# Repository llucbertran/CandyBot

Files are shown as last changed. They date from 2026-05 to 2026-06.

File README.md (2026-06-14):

# CandyBot

A voice-controlled candy dispenser built on a Raspberry Pi. A user asks for sweets out
loud — in **Catalan or Spanish** — and the robot serves the requested colours and amounts.
It also sorts itself: a rotating tray feeds Skittles one by one past a camera, reads
each colour, and drops it into the matching container.

Developed for the **Robotics Lab (RLP)** course at the Universitat Autònoma de Barcelona.

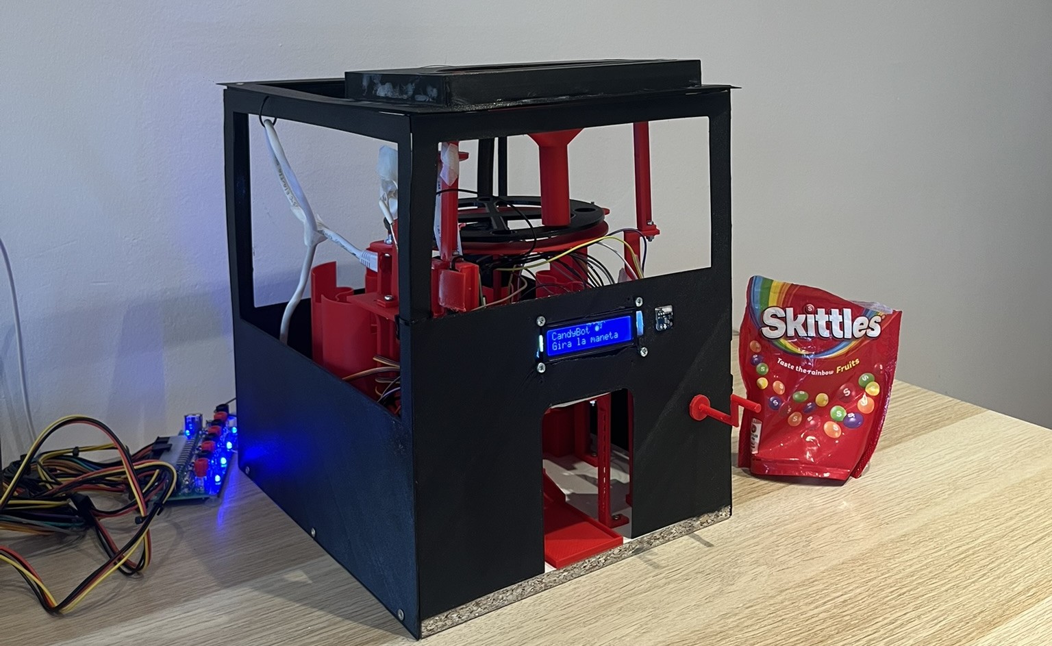
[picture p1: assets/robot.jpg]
CandyBot


[▶ Watch the demo](https://youtu.be/PrirMlMhzKU) *(Catalan with English subtitles)*

> **Autism & HRI.** Sorting and ordering objects is a well-documented self-regulatory
> behavior across the autism spectrum — it introduces predictability into a sensory
> environment that can feel overwhelming, and the act of categorising provides a
> satisfying, calming loop. CandyBot engages that same tendency in a playful context,
> while also offering a novel interaction modality: voice combined with a physical crank,
> which reduces the social pressure of direct human interaction.
>
> Color choices were informed by consultations with professionals in the field. Research
> shows that highly saturated or bright colors can be overstimulating for many individuals
> with ASD, while neutral, muted tones tend to be more comfortable. That said, autism is
> a broad spectrum and no single palette works universally — a conclusion reinforced by
> the professionals consulted during development. The robot's exterior is therefore black:
> visually quiet, non-imposing, and unobtrusive in any environment. The interior uses red
> accents to draw the user's attention and spark curiosity, without making the robot
> visually dominant in the space around it.

---

# Table of Contents

- [How it works](#how-it-works)
- [System architecture](#system-architecture)
  - [Pi software (BotSoftware)](#pi-software-botsoftware)
  - [Cloud API](#cloud-api)
- [Colour vision](#colour-vision)
  - [Detection pipeline](#detection-pipeline)
  - [HSV classification](#hsv-classification)
- [3D designs](#3d-designs)
- [Dispensing flow](#dispensing-flow)
- [Reload / self-sorting flow](#reload--self-sorting-flow)
- [Stock management](#stock-management)
- [Repository layout](#repository-layout)
- [Hardware](#hardware)
  - [Bill of materials](#bill-of-materials)
  - [Servo channel map](#servo-channel-map)
  - [Wiring defaults](#wiring-defaults)
- [The API](#the-api)
  - [Endpoint reference](#endpoint-reference)
  - [LLM prompt design](#llm-prompt-design)
  - [Deployment](#deployment)
- [Running the robot](#running-the-robot)
  - [Requirements](#requirements)
  - [Configuration](#configuration)
  - [Start](#start)
  - [Testing subsystems individually](#testing-subsystems-individually)
  - [Developing without hardware](#developing-without-hardware)
- [Team](#team)
- [License](#license)

---

# How it works

```
┌──────────────────────────────────────────────────────────────────┐
│  1. User turns crank   →  reed switch pulses  →  Pi starts rec.  │
│  2. Crank stops        →  WAV clip posted to Cloud API           │
│  3. API: STT           →  Gemini LLM          →  JSON command    │
│  4. Pi: dispense / reload / cancel            →  LCD feedback    │
└──────────────────────────────────────────────────────────────────┘
```

1. **Crank input.** A magnet sweeps past a reed switch once per revolution.
   The Pi counts pulses to detect user activity and starts recording automatically
   — no buttons, no touch screen.

2. **Recording.** While the crank is turning, audio is streamed to a buffer.
   When the crank stops, the clip is closed and sent as a WAV file to the
   CandyBot API over HTTPS.

3. **Language understanding.** The API pipeline has two stages:
   - **Speech-to-Text (Google STT v2)** transcribes the audio, tuned for Catalan
     (`ca-ES`).
   - **Gemini 2.5 Flash (Vertex AI)** reads the transcript and emits a strict JSON
     command describing what the user asked for.

4. **Execution.** The Pi interprets the JSON command and runs the matching flow:
   dispense specific colours and amounts, run the self-sorting reload routine, or
   do nothing if the intent was unclear.

Throughout the interaction the LCD screen shows the current state (idle, listening,
dispensing a colour, low stock warning, etc.).

---

# System architecture

## Pi software (BotSoftware)

The on-device code follows a **controller-per-subsystem** pattern. Each controller
owns one piece of hardware and exposes a small, stable interface to the rest of
the system.

```
BotSoftware/main.py
  │
  ├── crank_controller   — GPIO reed switch, wait_for_turn(), is_turning()
  ├── display_controller — 16×2 LCD, named states (idle, listening, dispensing…)
  ├── candy_controller   — stock check → servo dispatch → stock update
  ├── reload_controller  — disk + camera loop with voice-cancel support
  ├── servo_controller   — PCA9685 driver, dispense(color, qty), ramp_to(color)
  └── vision_controller  — picamera2 frame capture + ROI colour classification
```

The main loop is intentionally simple:

```python
while True:
    display.idle()
    crank.wait_for_turn()          # blocks until crank spins
    display.listening()
    response = api_client.record_and_send_while(crank.is_turning)

    if response["action"] == "dispense":
        candy_controller.dispense(response["items"])
    elif response["action"] == "reload":
        reload_controller.reload_with_voice_cancel()
    # cancel / nothing → loop back
```

## Cloud API

The API is a **FastAPI** application containerised with Docker and deployed to
**Google Cloud Run**. It is stateless: each request is fully self-contained.

```
POST /v1/command
  │
  ├── validate content-type and file size
  ├── Google STT v2  →  transcript (str)
  ├── Gemini 2.5 Flash  →  raw JSON (str)
  ├── pydantic parse + validate  →  CandyBotResponse
  └── return JSON response
```

Request authentication uses a shared secret passed in the `X-API-Token` header.
Timing for each stage (STT, LLM, total) is logged at INFO level on every request.

---

# Colour vision

## Detection pipeline

The vision system runs a **persistent picamera2 stream** at ~30 fps with fixed
exposure and gain, ensuring colour consistency across frames. During reload, the
system inspects a small ROI at a fixed position in the frame — the point where
each candy slot passes under the lens.

```
picamera2 frame (640 × 480)
  │
  ├── extract ROI  (centred at 40 % × 50 % of frame, radius 7 % of width)
  ├── convert BGR → HSV
  ├── compute median H, S, V across the ROI
  │
  ├── reject: H ≤ 12                        → disk hue wrapping near 0
  ├── reject: H 148–179 + V < 130 + S < 200 → black disk surface
  ├── reject: V < 20                         → too dark (shadow / gap)
  ├── reject: S < 120                        → empty slot / background
  │
  └── classify: nearest reference hue (circular distance) → colour name
```

A **two-consecutive-frames** confirmation rule (in `reload_controller`) prevents
stray reflections or partial coverage from triggering a wrong bin assignment.

## HSV classification

OpenCV uses H ∈ [0, 179]. Each colour is represented by a single reference hue;
classification picks the closest one by circular distance.

| Colour | Default reference hue |
|---|---|
| green  | 45 |
| yellow | 95 |
| orange | 121 |
| red | 135 |
| purple | 172 |

Reference hues are loaded at startup from `BotSoftware/VC/color_calibration.json`
if the file exists. Run `HW tests/calibrar_colores.py` to measure and save the
per-unit hues for your specific camera and lighting conditions.

---

# Dispensing flow

When the command action is `"dispense"`:

```
candy_controller.dispense(items)
  │
  ├── guard: items list empty?  →  display.empty_command()
  ├── check_availability(items) against SQLite stock
  │     not ok  →  display.low_stock(color, available)  →  return
  │
  └── for each item:
        display.dispensing(color, qty)
        servo_controller.dispense(color, qty)   # SG90 pulses
        (loop qty times, one candy per pulse)
  │
  └── consume_from_command(items)   →  update SQLite
```

`servo_controller.dispense` sends a calibrated angular pulse to the SG90 on the
matching PCA9685 channel. Each pulse ejects exactly one Skittle from its cylinder.
The number of pulses equals the requested quantity.

---

# Reload / self-sorting flow

When the command action is `"reload"`, the robot enters the self-sorting routine.
A background thread simultaneously listens for a voice `"cancel"` command so the
user can stop the reload early by turning the crank and saying "para".

```
reload_with_voice_cancel()
  │
  ├── spawn listener thread:
  │     while not cancelled and not done:
  │         if crank.is_turning():
  │             record → API → if action=="cancel": set cancel_event
  │
  └── reload_once(should_cancel=cancel_event.is_set)
        │
        ├── vision_controller.start()   (open camera)
        ├── servo_controller.disk_start()   (continuous servo)
        │
        ├── loop:
        │     detect_color() → color
        │     require two consecutive same-colour frames (anti-flicker)
        │     if confirmed and armed:
        │         sleep DISK_RAMP_DELAY_S   (candy travels to ramp)
        │         servo_controller.ramp_to(color)
        │         candy_stock.add_candy(color, 1)
        │         display.reloading(stock, color)
        │         armed = False
        │     if no candy for DISK_REARM_S  →  armed = True
        │     if no candy for DISK_EMPTY_TIMEOUT_S  →  break (tray empty)
        │     sleep CAMERA_INTERVAL_S
        │
        └── disk_stop() · ramp_center() · vision_controller.release()
```

All timing constants (`DISK_RAMP_DELAY_S`, `DISK_REARM_S`, `DISK_EMPTY_TIMEOUT_S`,
`CAMERA_INTERVAL_S`) are defined in `BotSoftware/config/servo_config.py` so they
can be tuned without touching controller logic.

---

# Stock management

Stock is persisted in a **SQLite database** (`BotSoftware/candy_stock.db`).
The schema is a single table:

```sql
CREATE TABLE stock (
    color    TEXT PRIMARY KEY,
    quantity INTEGER NOT NULL DEFAULT 0 CHECK (quantity >= 0)
);
```

Five rows are seeded on first use (red, orange, yellow, green, purple).
The public API exposed by `BotSoftware/models/candy_stock.py`:

| Function | Description |
|---|---|
| `get_stock(color=None)` | Return quantity for one colour, or a dict of all five |
| `add_candy(color, qty)` | Increment stock (called by reload loop) |
| `remove_candy(color, qty)` | Decrement stock (called after dispensing) |
| `set_stock(color, qty)` | Overwrite a single colour (calibration / tests) |
| `set_all(qty)` | Set every colour to the same value |
| `reset()` | Empty all stock (every colour → 0) |
| `check_availability(items)` | Return `{ok, missing}` before dispensing |
| `consume_from_command(items)` | Atomic check-and-remove for a full command |

The `CHECK (quantity >= 0)` constraint in SQLite means stock can never go
negative at the database level, even if a software bug skips the availability
check.

---

# Repository layout

```
CandyBot/
│
├── BotSoftware/                Code that runs on the Raspberry Pi
│   ├── main.py                 Entry point — the main loop
│   ├── candy_stock.db          SQLite stock database (created on first run)
│   ├── config/
│   │   └── servo_config.py     I2C addresses, GPIO pins, timing constants
│   ├── controllers/
│   │   ├── candy_controller.py   Dispense flow
│   │   ├── crank_controller.py   Reed switch input
│   │   ├── display_controller.py LCD states
│   │   ├── reload_controller.py  Self-sorting flow
│   │   ├── servo_controller.py   PCA9685 / SG90 driver
│   │   └── vision_controller.py  Camera capture + colour classification
│   ├── models/
│   │   └── candy_stock.py        SQLite stock access layer
│   ├── services/
│   │   └── api_client.py         Audio recording + HTTP post to API
│   └── VC/                       Vision module
│       ├── camera_stream.py      Picamera2 continuous capture
│       ├── color_centre.py       ROI extraction + HSV hue classification
│       ├── color_calibration.json  Per-unit hue calibration (generated)
│       └── prototypes/           Standalone development scripts
│
├── Software/
│   └── Api/                        Cloud service (FastAPI + Docker)
│       ├── main.py                 FastAPI app, /v1/command endpoint
│       ├── config.py               Settings via environment variables
│       ├── models.py               Pydantic response schema
│       ├── Dockerfile              Container definition
│       ├── pyproject.toml          Poetry dependencies
│       └── services/
│           ├── llm_client.py       Vertex AI / Gemini 2.5 Flash client
│           ├── speech_to_text.py   Google STT v2 client
│           ├── parse_and_validate.py   JSON parse + pydantic validation
│           ├── prompt_loader.py    Load system prompt from file
│           └── system_prompt.txt   LLM system prompt
│
├── HW tests/                   Standalone hardware verification scripts
│   ├── test_palanca.py         Crank / reed switch
│   ├── test_ordenar.py         Full sorting cycle (tray + camera + ramp)
│   ├── test_pantalla.py        LCD display
│   ├── control_servo_basic.py  Raw servo movement
│   ├── control_pantallaLCD_basic.py  Raw LCD output
│   ├── calibrar_colores.py     Calibrate per-unit colour reference hues
│   └── ver_colores.py          Live colour detection preview
│
└── 3D Models/                  Printable parts (.stl) — being finalised
```

---

# Hardware

## Bill of materials

| Qty | Part | Role |
|-----|---|---|
| 1 | Raspberry Pi 4 (4 GB) | Central controller |
| 1 | Raspberry Pi Camera Module v2 | Colour detection |
| 1 | PCA9685 16-ch PWM driver (I2C) | Servo bus |
| 5 | SG90 servo | Candy dispensers (one per colour) |
| 1 | SG90 servo | Directional ramp |
| 1 | Continuous-rotation servo (360°) | Sorting tray disk |
| 1 | 16×2 character LCD + PCF8574 I2C backpack | User feedback |
| 1 | USB sound card + electret microphone | Voice input |
| 1 | Reed switch + neodymium magnet | Crank activity detection |
| — | 5 V power supply (≥ 3 A) | Servo rail |

## Servo channel map

| PCA9685 channel | Servo | Colour |
|---|---|---|
| 0 | Dispenser | green |
| 1 | Dispenser | purple |
| 2 | Dispenser | red |
| 3 | Dispenser | orange |
| 4 | Dispenser | yellow |
| 5 | Ramp | — |
| 6 | Sorting disk | — |

Channels 5 and 6 are assigned during assembly and may differ per build.
Verify against `BotSoftware/config/servo_config.py` before first run.

## Wiring defaults

| Component | Default address / pin |
|---|---|
| PCA9685 | I2C `0x40` |
| LCD | I2C `0x3F` |
| Reed switch | GPIO 17 (BCM) |
| Microphone | ALSA `plughw:1,0` |
| Camera | Pi camera port (CSI), via picamera2 |

Find your microphone device with `arecord -l`. Update `servo_config.py` if your
I2C addresses differ (use `i2cdetect -y 1` to scan the bus).

---

# 3D designs

All structural and mechanical parts are custom-designed for this project from
scratch. Designs stem from research and inspiration from existing mechanisms,
adapted and shaped to fit CandyBot's specific requirements.

The final design comprises around **29 distinct printable parts**, though many more
were designed along the way — early prototypes, intermediate versions, and parts
that were later corrected or replaced as the design evolved.

Each part went through several design iterations, guided by two priorities:
**ease of maintenance** — individual parts can be removed and replaced without
disassembling the whole robot — and **robust assembly**, using screwed joints
throughout to avoid snap fits that degrade over time.

Dimensional accuracy was especially critical for the moving mechanisms. The
sorting tray, the dispensers, and the directional ramp all depend on tight
tolerances: even small deviations in a sliding or rotating part introduce
friction that disrupts the timing of the sorting cycle.

<table>
  <tr>
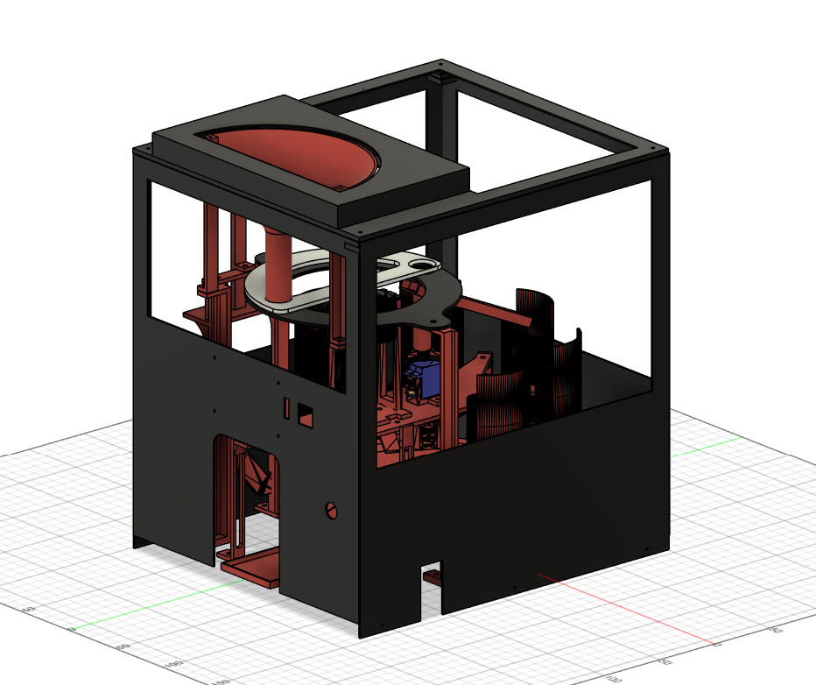
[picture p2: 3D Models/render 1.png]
    <td></td>
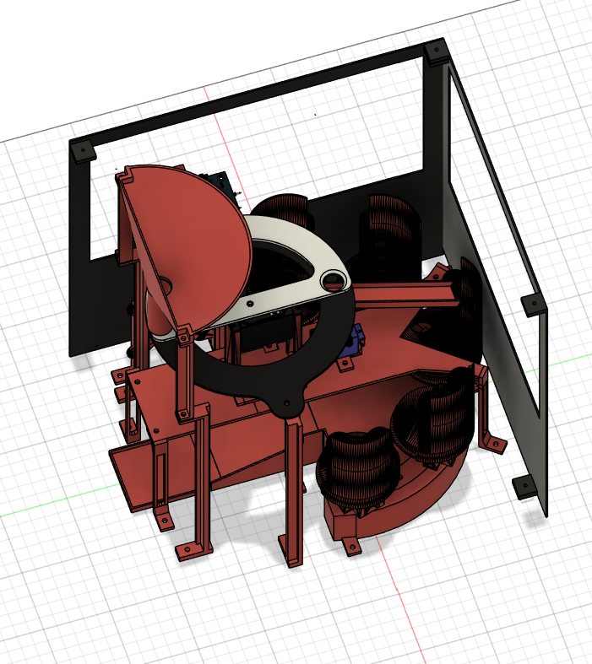
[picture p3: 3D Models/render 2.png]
    <td></td>
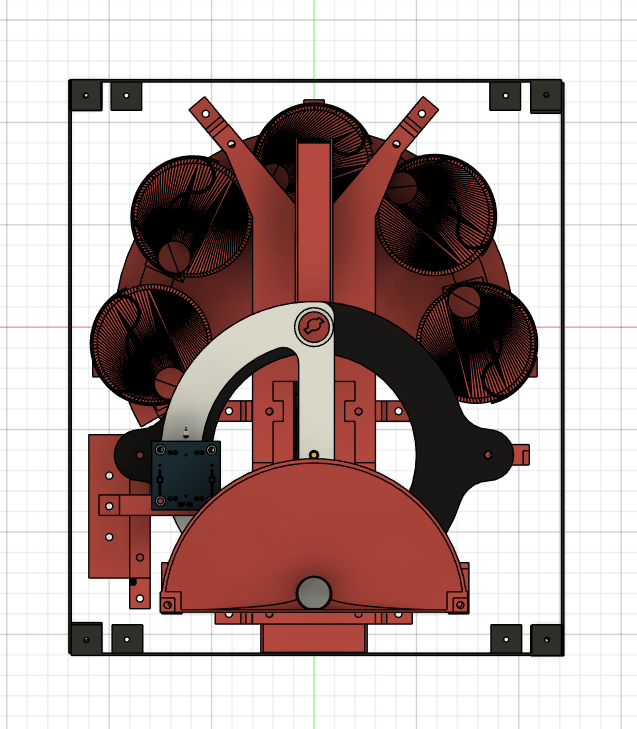
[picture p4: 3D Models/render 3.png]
    <td></td>
  </tr>
  <tr>
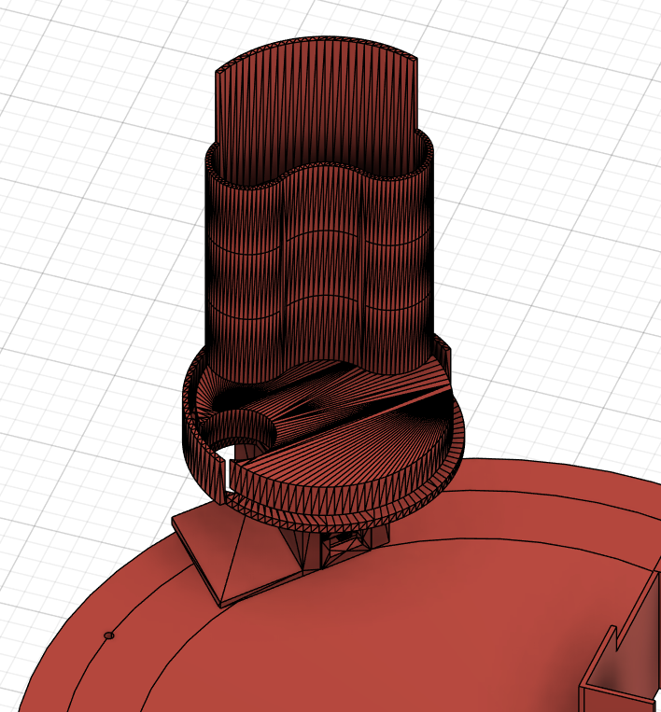
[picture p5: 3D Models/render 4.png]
    <td></td>
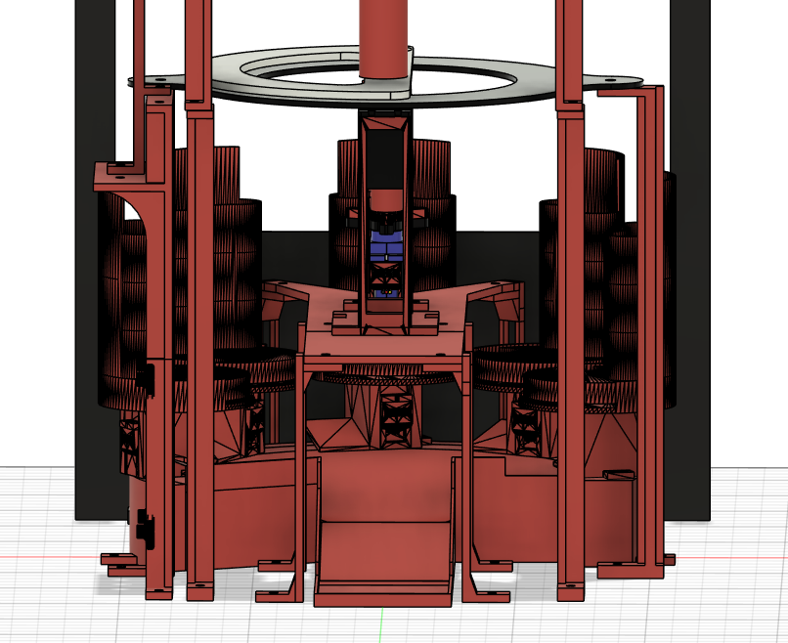
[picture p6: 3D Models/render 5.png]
    <td></td>
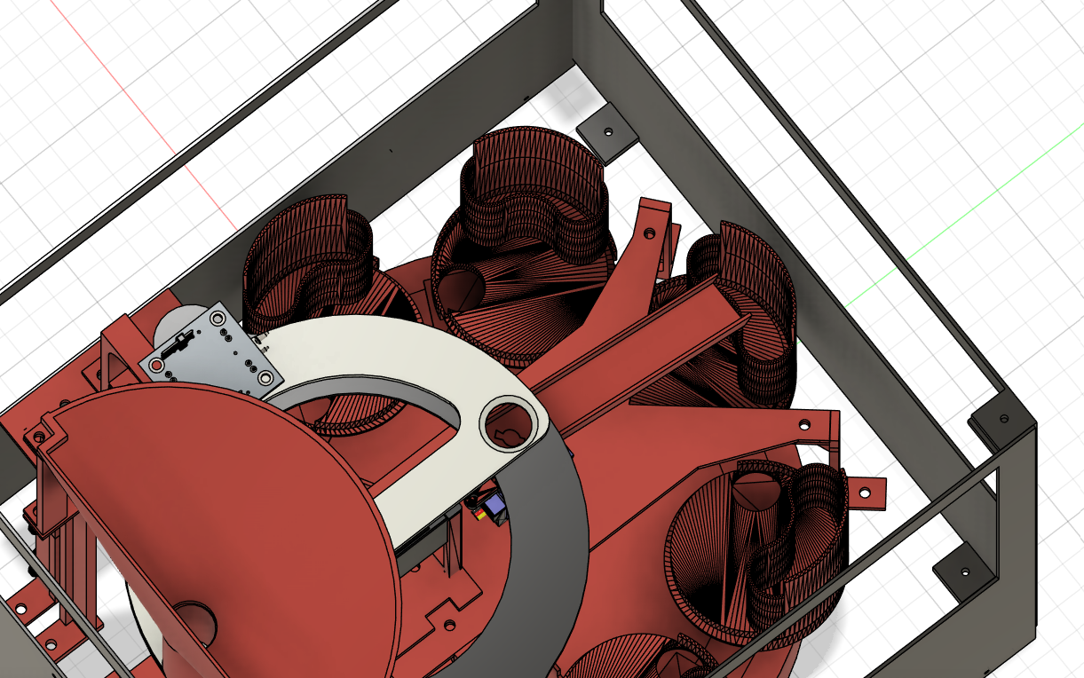
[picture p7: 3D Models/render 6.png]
    <td></td>
  </tr>
</table>

STL files are available in `3D Models/`.

> **Note:** The sorting disk shown in some renders is an earlier single-slot design that required the disk to oscillate back and forth for each candy. The final version uses a **continuous-rotation disk with 4 slots**, eliminating the back-and-forth motion and multiplying sorting throughput by 4×.

---

# The API

## Endpoint reference

### `GET /health`

Health check. Returns `{"status": "ok", "service": "CandyBot API"}`. No authentication required.

### `POST /v1/command`

Convert a voice clip to a structured candy command.

**Authentication:** `X-API-Token: <token>` header (required).

**Request body:** `multipart/form-data`

| Field | Type | Description |
|---|---|---|
| `audio` | file | WAV audio clip. Content-Type must start with `audio/`. Max size controlled by `MAX_AUDIO_BYTES` env var. |

**Response** `200 OK`:

```json
{
  "action":     "dispense",
  "confidence": 0.95,
  "items": [
    { "color": "red",    "quantity": 2 },
    { "color": "yellow", "quantity": 1 }
  ]
}
```

| Field | Type | Values |
|---|---|---|
| `action` | string | `dispense` · `reload` · `cancel` · `nothing` |
| `confidence` | float | 0.0 – 1.0, LLM self-reported |
| `items` | array | Only present when `action == "dispense"` |

**Error responses:**

| Status | Cause |
|---|---|
| 400 | Invalid content-type, empty file, or file too large |
| 401 | Missing or invalid `X-API-Token` |
| 422 | LLM returned a response that failed schema validation |
| 502 | Upstream STT or LLM request failed |

## LLM prompt design

The system prompt (`Software/Api/services/system_prompt.txt`) instructs Gemini to:

- Output **only valid JSON**, matching the `CandyBotResponse` schema.
- Map colour names from Catalan and Spanish to the canonical English set
  (`red`, `orange`, `yellow`, `green`, `purple`).
- Set `action = "nothing"` when the intent is unclear or unrelated.
- Set `action = "cancel"` when the user explicitly wants to stop.
- Report a `confidence` value reflecting certainty about the parsed intent.

The LLM is called with `response_mime_type: "application/json"` so that
Gemini returns structured output natively, reducing parse failures.

## Deployment

The API is containerised and tested to run on **Google Cloud Run** (minimum
512 MB memory; the STT and Vertex AI clients add no in-process weight beyond
the Python SDK).

**Environment variables:**

| Variable | Required | Default | Description |
|---|---|---|---|
| `GCP_PROJECT` | yes | — | Google Cloud project ID |
| `GCP_LOCATION` | no | `europe-west1` | Region for Vertex AI |
| `API_TOKEN` | yes | — | Shared secret for authentication |
| `MAX_AUDIO_BYTES` | no | `10485760` | Max upload size (10 MB) |
| `LLM_MODEL` | no | `gemini-2.5-flash` | Vertex AI model name |

**Required Google Cloud APIs:** Speech-to-Text v2, Vertex AI.

Build and run locally:

```bash
cd Api
docker build -t candybot-api .
docker run -p 8080:8080 \
  -e GCP_PROJECT=my-project \
  -e GCP_LOCATION=europe-west1 \
  -e API_TOKEN=mysecret \
  candybot-api
```

---

# Running the robot

## Requirements

- Raspberry Pi running **Raspberry Pi OS** (Bookworm or later), Python 3.11+
- Hardware connected and verified (see [Hardware](#hardware))
- Python packages:

  ```
  requests
  python-dotenv
  gpiozero
  adafruit-servokit
  RPLCD
  opencv-python
  picamera2
  ```

- System tools (pre-installed on Raspberry Pi OS):

  ```
  arecord   # ALSA audio recording
  ```

Install Python dependencies:

```bash
pip install requests python-dotenv gpiozero adafruit-servokit RPLCD opencv-python picamera2
```

## Configuration

Create a `.env` file inside `BotSoftware/`:

```env
API_URL=https://<your-cloud-run-url>/v1/command
API_TOKEN=<the same token configured in the API>
```

Review `BotSoftware/config/servo_config.py` and verify that I2C addresses,
GPIO pin, microphone device, and servo channels match your build before
the first run.

## Start

```bash
python -m BotSoftware.main
```

The robot enters idle state, waits for crank input, then loops indefinitely.

## Testing subsystems individually

Before a full run it is recommended to verify each subsystem in isolation:

```bash
# Crank / reed switch
python "HW tests/test_palanca.py"

# LCD display
python "HW tests/test_pantalla.py"

# Sorting cycle: tray motor, camera, ramp
python "HW tests/test_ordenar.py"

# Dispense one candy of each colour
python -m BotSoftware.controllers.servo_controller

# Microphone + speech-to-text smoke test
python "HW tests/speech_to_text.py"

# Raw servo movement
python "HW tests/control_servo_basic.py"
```

## Developing without hardware

Every controller guards its hardware import with a try/except. If a component
(PCA9685, LCD, camera, GPIO) is not found, the controller prints a `[NO HW]`
notice and continues in **simulation mode** — methods become no-ops or return
dummy values. This means the full software stack can be run and tested on any
machine, even without a Raspberry Pi attached.

---

# Team

Developed at the Robotics Lab (RLP), Universitat Autònoma de Barcelona.

| Role | Name |
|---|---|
| Software Lead | Pol Montesó Tarrida |
| Hardware Lead | Xavi Umbert Medina |
| 3D Parts & Mechanical Lead / Product Owner | Lluc Bertran Canicio |
| Testing & Validation Lead | Matheus Henrique Mingorance Maciel |
| Vision Lead | Matheus Henrique Mingorance Maciel |

See [Roles.md](Roles.md) for full role descriptions.

---

# License

MIT

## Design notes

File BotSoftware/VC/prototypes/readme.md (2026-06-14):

> **Nota:** Aquesta carpeta conté prototips inicials de visió per computador. No
> formen part del sistema final, que utilitza `BotSoftware/VC/color_centre.py` i
> `camera_stream.py`. Es conserven com a documentació de la investigació.

# Detecció de color de Skittles amb Visió per Computador

Aquest directori conté un petit programa en Python per detectar automàticament el color d'un Skittle a partir d'imatges capturades amb càmera.

El codi utilitza **OpenCV** i **NumPy** per processar les imatges, localitzar l'objecte principal i classificar el seu color mitjançant l'espai de color **HSV**.

---

## Objectiu

L'objectiu és provar una primera versió del sistema de visió per computador que més endavant es podria executar en una Raspberry Pi amb càmera.

En aquesta prova, no s'utilitza encara la Raspberry Pi. Les imatges ja estan capturades prèviament i el programa les analitza des d'un ordinador.

El sistema:

1. Llegeix totes les imatges d'una carpeta.
2. Detecta l'objecte circular que correspon al Skittle.
3. Calcula el color dominant del Skittle.
4. Classifica el color.
5. Mostra la imatge amb la detecció marcada.
6. Imprimeix un resum final amb el color detectat per cada imatge.

---

## Fitxers

Exemple d'estructura de la carpeta:

```txt
VC/
├── detectar_colors.py
├── prova1.jpg
├── prova2.jpg
├── prova3.jpg
├── prova4.jpg
├── prova5.jpg
├── prova6.jpg
└── README.md
```

Les imatges de prova són:

```txt
prova1.jpg
prova2.jpg
prova3.jpg
prova4.jpg
prova5.jpg
prova6.jpg
```

Cada imatge conté un Skittle d'un color diferent.

---

## Requisits

Cal tenir instal·lat Python i les llibreries següents:

```bash
pip install opencv-python numpy
```

Si `pip` no funciona directament, es pot provar:

```bash
py -m pip install opencv-python numpy
```

---

## Execució

Des de la carpeta on es troben les imatges i el fitxer `detectar_colors.py`, executar:

```bash
python detectar_colors.py
```

o bé:

```bash
py detectar_colors.py
```

---

## Funcionament general del codi

El programa segueix aquest procés:

```txt
Llegir imatge
↓
Convertir imatge de BGR a HSV
↓
Crear una màscara de zones amb color viu
↓
Buscar contorns
↓
Seleccionar el contorn que més sembla un Skittle
↓
Calcular el color dominant
↓
Classificar el color
↓
Mostrar resultat
```

---

## Per què s'utilitza HSV?

Les imatges que llegeix OpenCV estan en format **BGR**, però per detectar colors és més còmode utilitzar **HSV**.

HSV separa la informació en:

```txt
H = Hue / To del color
S = Saturation / Intensitat del color
V = Value / Brillantor
```

Això permet diferenciar millor colors com:

- blau,
- verd,
- groc,
- taronja,
- vermell,
- marró.

Per exemple, dos colors poden semblar semblants en RGB, però en HSV es poden separar millor segons el seu to, saturació i brillantor.

---

## Lectura robusta d'imatges

El codi no utilitza directament:

```python
cv2.imread()
```

perquè en Windows pot donar problemes quan la ruta conté accents o caràcters especials, com per exemple:

```txt
Pràctiques
```

Per això es fa servir una lectura més robusta:

```python
datos = np.fromfile(str(ruta_imagen), dtype=np.uint8)
imagen = cv2.imdecode(datos, cv2.IMREAD_COLOR)
```

Això evita errors de lectura de fitxers en rutes amb accents.

---

## Cerca automàtica d'imatges

El programa busca automàticament imatges dins la carpeta actual.

Accepta extensions:

```txt
.jpg
.jpeg
.JPG
.JPEG
.png
.PNG
```

A més, evita duplicats, ja que en Windows les extensions `.jpg` i `.JPG` poden arribar a detectar el mateix fitxer dues vegades.

---

## Detecció del Skittle

Primer es crea una màscara per detectar zones amb color viu:

```python
lower = np.array([0, 70, 45])
upper = np.array([179, 255, 255])
mascara = cv2.inRange(hsv, lower, upper)
```

Aquesta màscara intenta quedar-se amb les parts de la imatge que tenen color suficient i descartar parts com:

- fons de fusta,
- ombres,
- zones grises,
- reflexos poc saturats.

Després es busquen contorns amb:

```python
cv2.findContours()
```

---

## Selecció del contorn correcte

Inicialment, el programa agafava el contorn més gran, però això podia fallar perquè altres zones de la imatge, com objectes a la part inferior, també tenien colors vius.

Per solucionar-ho, ara el programa selecciona el contorn que més sembla un Skittle segons diversos criteris:

```txt
- Ha de tenir una àrea raonable.
- Ha de ser relativament circular.
- No pot tocar les vores de la imatge.
- No pot ser una regió massa gran.
- No pot ser massa allargat.
- Es prioritzen objectes propers al centre de la imatge.
```

Això permet evitar detectar erròniament altres objectes de la imatge.

---

## Càlcul del color dominant

Un cop detectat el contorn del Skittle, es crea una màscara només per aquest objecte.

Després es calculen els valors HSV dels píxels que pertanyen al Skittle.

Per evitar que els reflexos blancs o les ombres afectin massa, es filtra la saturació i es fa servir la **mediana** en comptes de la mitjana:

```python
h_median = float(np.median(pixels_h))
s_median = float(np.median(pixels_s))
v_median = float(np.median(pixels_v))
```

La mediana és més robusta que la mitjana perquè no es veu tan afectada per valors extrems, com reflexos molt blancs o zones molt fosques.

---

## Classificació del color

La funció principal de classificació és:

```python
clasificar_color_hsv(h, s, v)
```

Aquesta funció rep els valors HSV dominants i retorna un color.

Els rangs utilitzats són aproximadament:

```txt
H < 10 o H >= 170     -> vermell
10 <= H < 24          -> taronja
24 <= H < 40          -> groc
40 <= H < 85          -> verd
85 <= H < 130         -> blau
130 <= H < 160        -> lila / morat
```

També s'ha afegit una regla especial per detectar el color marró.

---

## Diferència entre vermell i marró

En HSV, el marró pot caure en una zona semblant al vermell o taronja. Per això no n'hi ha prou amb mirar només el valor `H`.

En les imatges de prova:

```txt
marró   -> H proper al vermell/taronja, però amb V baix i S més baixa
vermell -> H proper al vermell, però amb V alta i S alta
```

Per això el codi detecta el marró així:

```python
if (h < 20 or h >= 170) and v < 130 and s < 180:
    return "marro"
```

És a dir:

```txt
Si sembla vermell/taronja,
però és fosc i menys saturat,
llavors es classifica com a marró.
```

---

## Visualització del resultat

Per cada imatge, el programa mostra una finestra amb:

- la imatge original,
- un rectangle verd al voltant del Skittle,
- un punt al centre aproximat,
- el nom del fitxer,
- el color detectat.

Exemple visual:

```txt
prova1.jpg: blau
```

Per passar a la següent imatge, cal prémer qualsevol tecla mentre la finestra d'OpenCV està seleccionada.

---

## Resultat esperat

Un exemple de sortida per terminal és:

```txt
Resultats:
------------------------------------------------------------
prova1.jpg -> blau (H=115.0, S=255.0, V=211.0)
prova2.jpg -> groc (H=28.0, S=249.0, V=221.0)
prova3.jpg -> marro (H=9.0, S=115.0, V=70.0)
prova4.jpg -> taronja (H=14.0, S=243.0, V=223.0)
prova5.jpg -> verd (H=77.0, S=238.0, V=191.0)
prova6.jpg -> vermell (H=176.0, S=224.0, V=201.0)

RESUM FINAL
------------------------------------------------------------
prova1.jpg -> blau
prova2.jpg -> groc
prova3.jpg -> marro
prova4.jpg -> taronja
prova5.jpg -> verd
prova6.jpg -> vermell
```

---

## Colors detectats

Actualment el codi pot classificar:

```txt
blau
groc
marro
taronja
verd
vermell
lila / morat
rosa / vermell clar
blanc / gris clar
molt fosc / ombra
```

Els colors principals de la prova són:

```txt
blau
groc
marro
taronja
verd
vermell
```

---

## Limitacions

Aquest sistema és una primera versió basada en regles HSV.

Pot fallar si:

- canvia molt la il·luminació,
- hi ha ombres fortes,
- el fons té colors semblants al Skittle,
- el Skittle està molt lluny o molt petit,
- hi ha més d'un objecte circular de color a la imatge,
- la càmera canvia molt la saturació o la brillantor.

Per un sistema final, seria recomanable:

- controlar millor la il·luminació,
- fixar la posició de la càmera,
- posar un fons més neutre,
- calibrar els rangs HSV amb més imatges,
- guardar exemples de cada color,
- provar amb vídeo en temps real.

---

## Possible evolució amb Raspberry Pi

Aquest codi és una prova local amb imatges ja capturades.

Més endavant, en una Raspberry Pi, el flux seria:

```txt
Capturar imatge amb la càmera
↓
Executar detecció de color
↓
Classificar el Skittle
↓
Enviar ordre al robot o mecanisme de separació
```

Per exemple:

```txt
Si color = vermell -> moure servo a posició 1
Si color = blau    -> moure servo a posició 2
Si color = verd    -> moure servo a posició 3
```

---

## Resum

Aquest codi implementa una primera versió funcional d'un detector de color per Skittles utilitzant visió per computador.

La detecció es basa en:

- OpenCV,
- conversió a HSV,
- màscares de color,
- detecció de contorns,
- selecció de formes circulars,
- classificació del color dominant.

És una base inicial per al sistema de separació automàtica de Skittles del projecte.

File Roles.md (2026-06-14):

## 👥 Team Roles

This project is developed as part of the Robotics Lab (RLP) at UAB.

- 💻 **Software Lead (SW Lead)**  
  Pol Montesó Tarrida  

- 🔩 **Hardware Lead (HW Lead)**  
  Xavi Umbert Medina  

- 🛠️ **3D Parts & Mechanical Lead + Product Owner (PO)**  
  Lluc Bertran Canicio  

- 🔬 **Testing & Validation Lead**  
  Matheus Henrique Mingorance Maciel  

- 👁️ **Vision Lead**  
  Matheus Henrique Mingorance Maciel

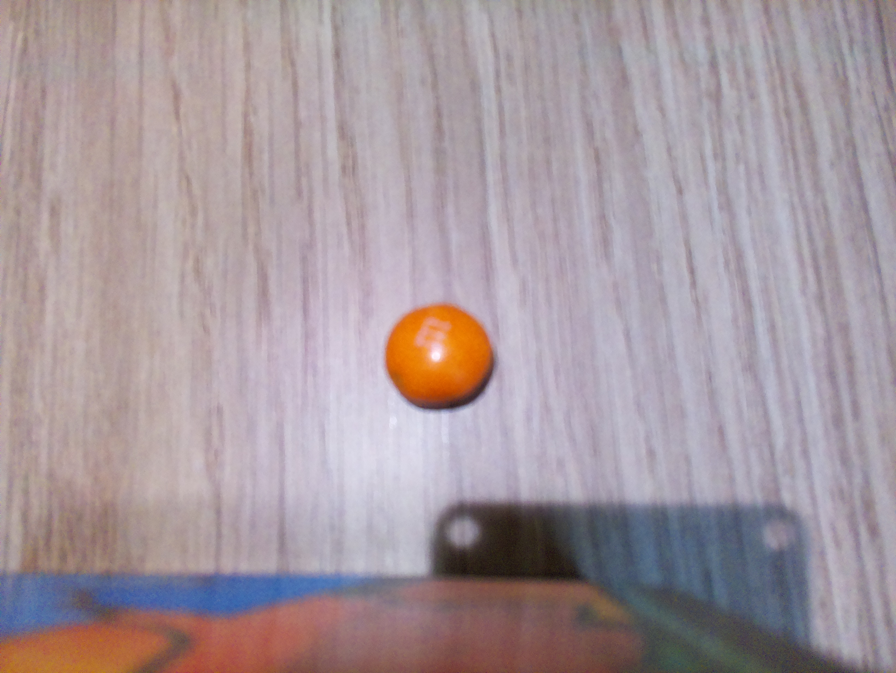
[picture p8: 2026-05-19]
BotSoftware/VC/prototypes/prova4.jpg

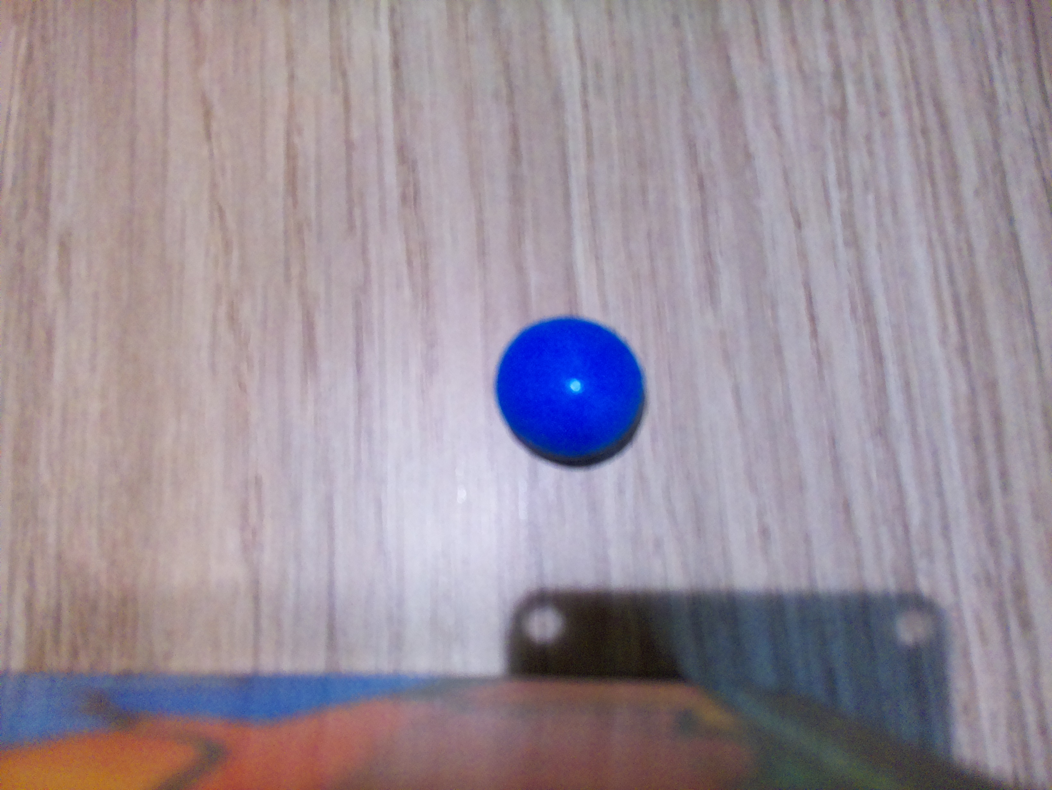
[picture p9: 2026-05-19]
BotSoftware/VC/prototypes/prova1.jpg

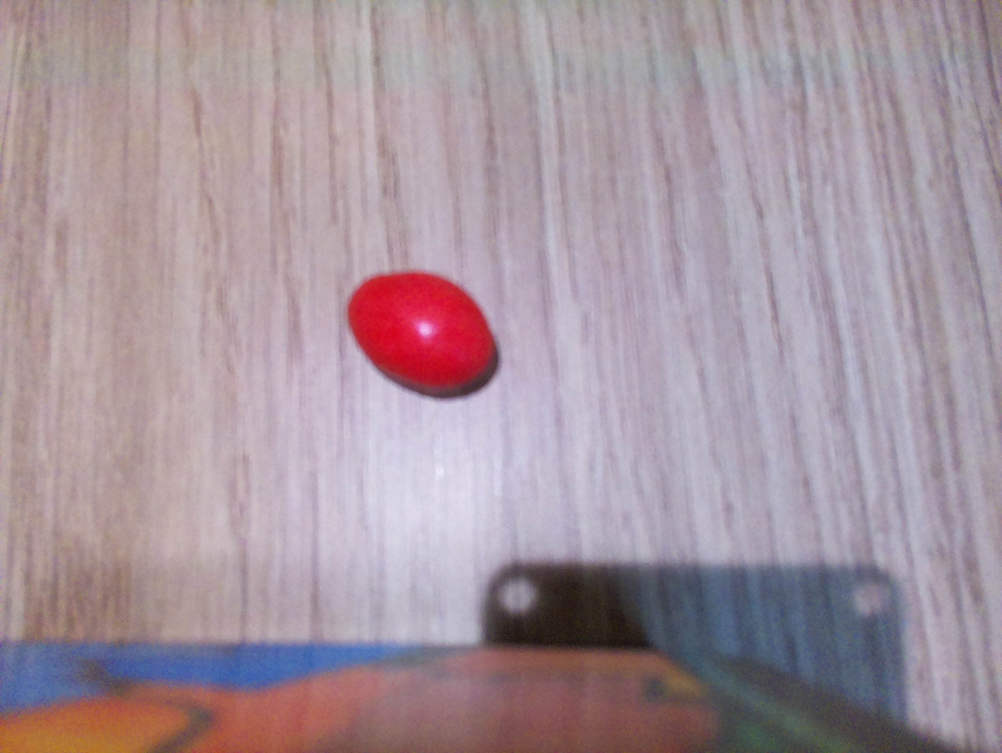
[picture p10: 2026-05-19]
BotSoftware/VC/prototypes/prova6.jpg

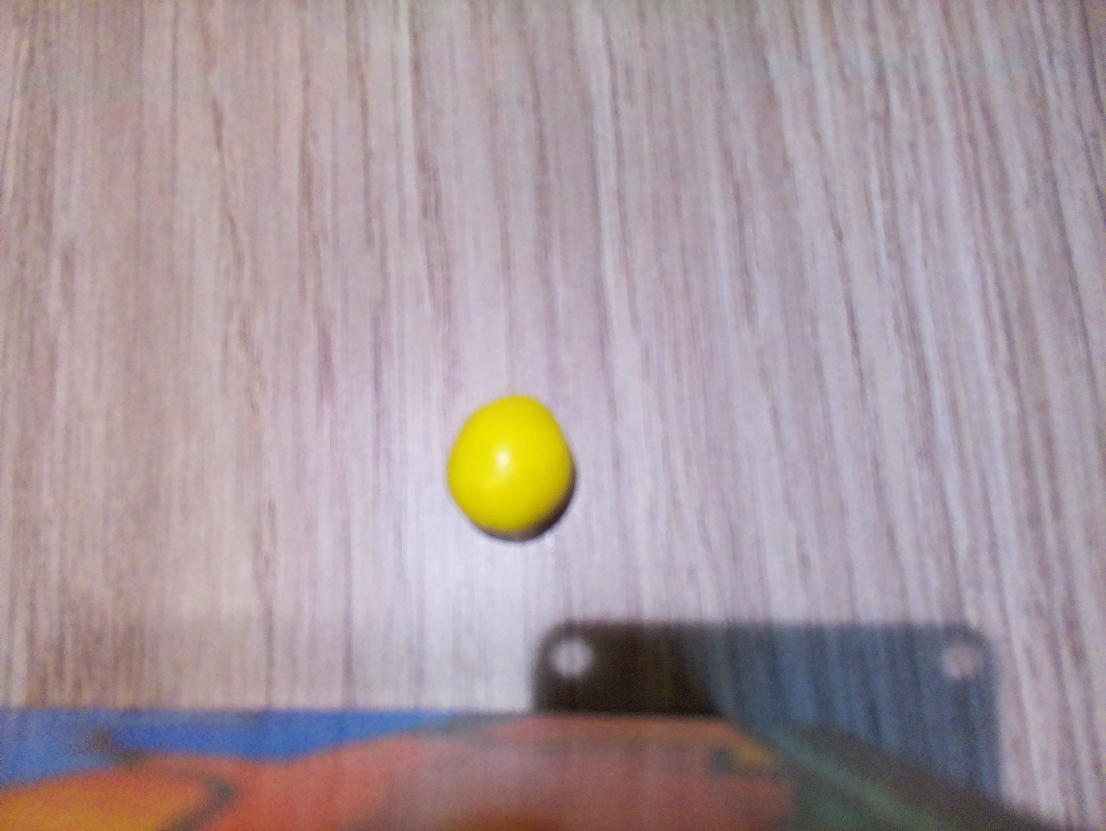
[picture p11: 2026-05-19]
BotSoftware/VC/prototypes/prova2.jpg

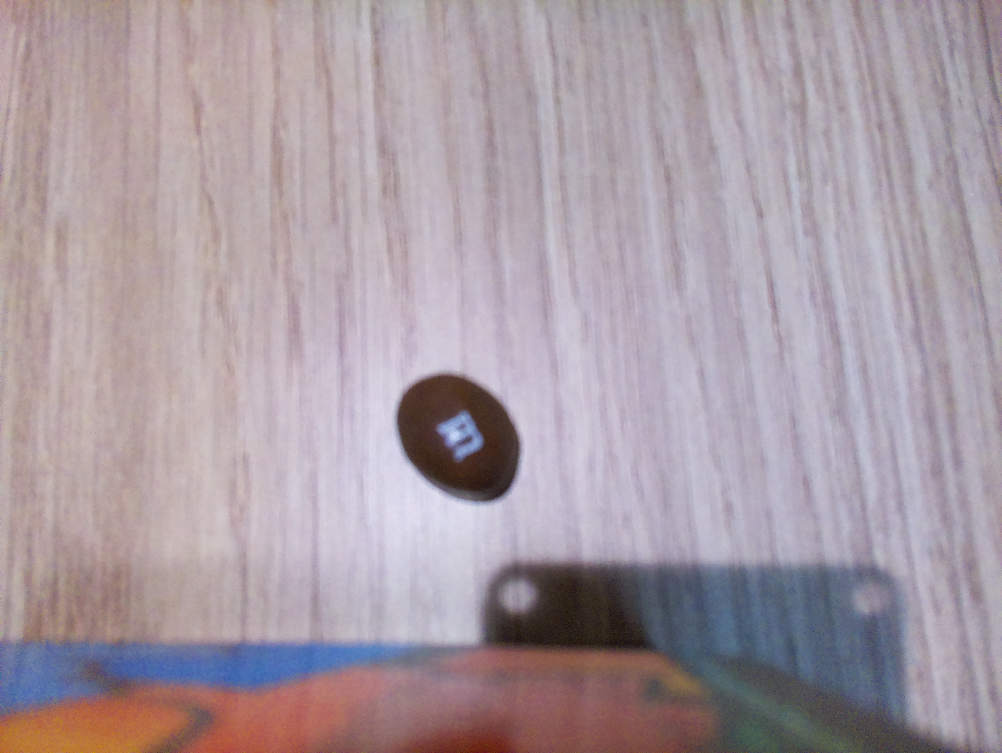
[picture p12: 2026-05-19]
BotSoftware/VC/prototypes/prova3.jpg

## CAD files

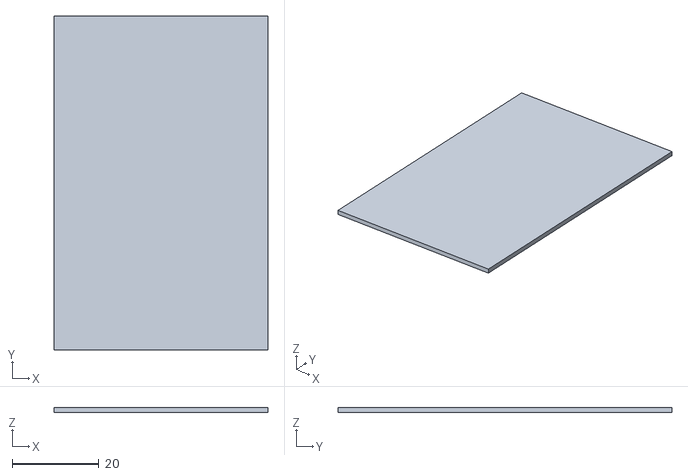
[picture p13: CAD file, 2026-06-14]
3D Models/main base ramp.stl
49.2 x 76.9 x 1.20

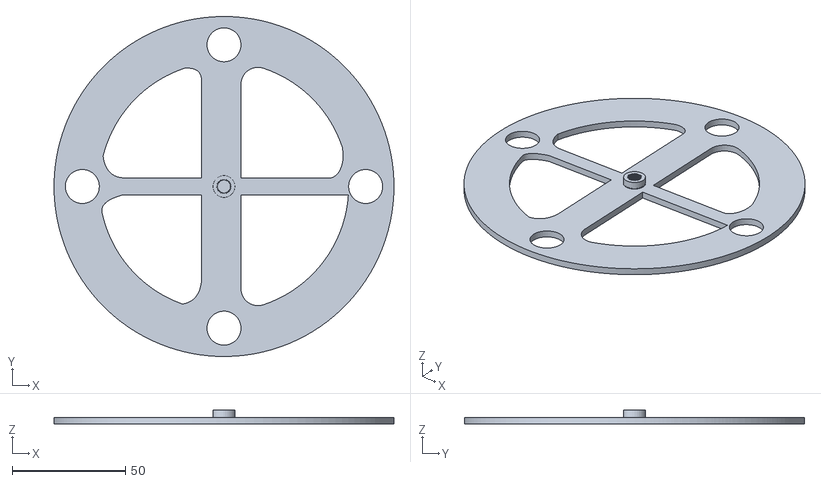
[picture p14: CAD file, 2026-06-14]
3D Models/main 4-hole disc.stl
150.0 x 150.0 x 6.30

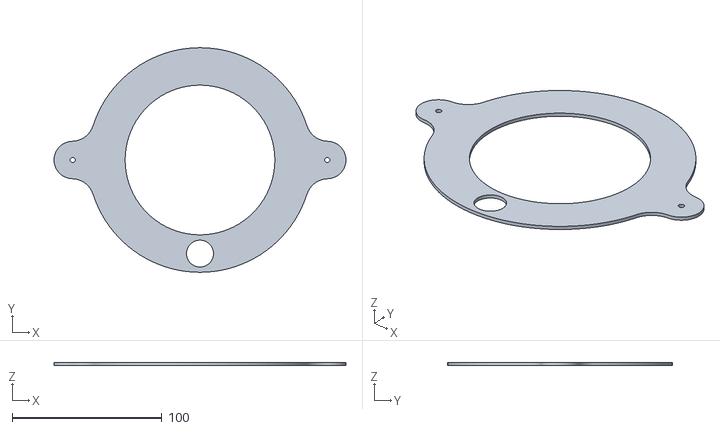
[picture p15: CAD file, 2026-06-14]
3D Models/main disc.stl
195.0 x 150.0 x 2.00

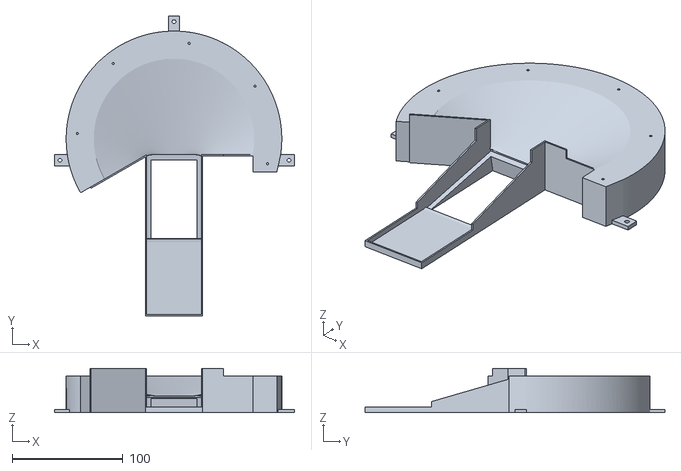
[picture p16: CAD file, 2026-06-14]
3D Models/main base.stl
217.0 x 271.0 x 40.0

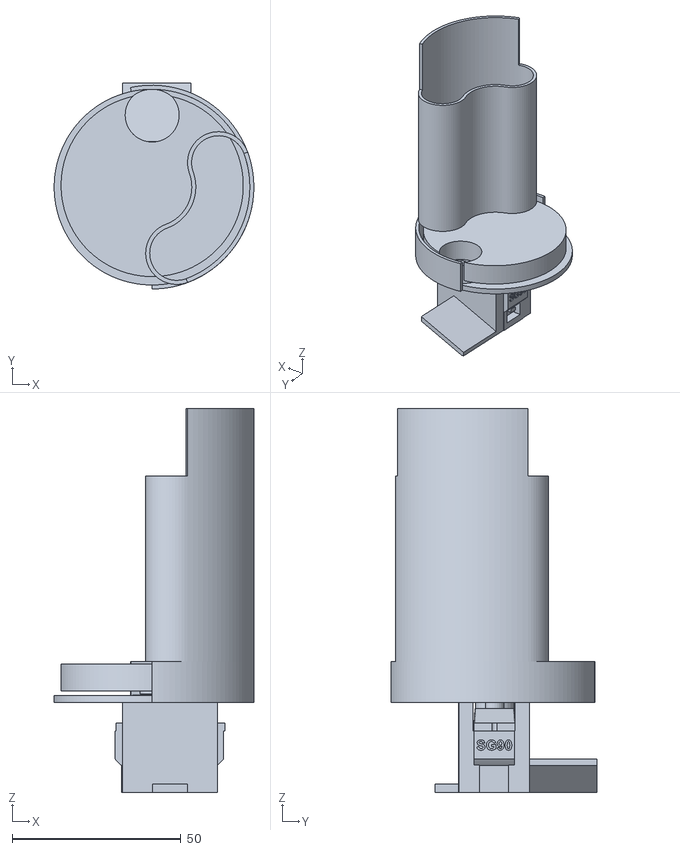
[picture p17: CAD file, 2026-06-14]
3D Models/assembly dispenser (non-printable).stl
59.2 x 61.1 x 113.8

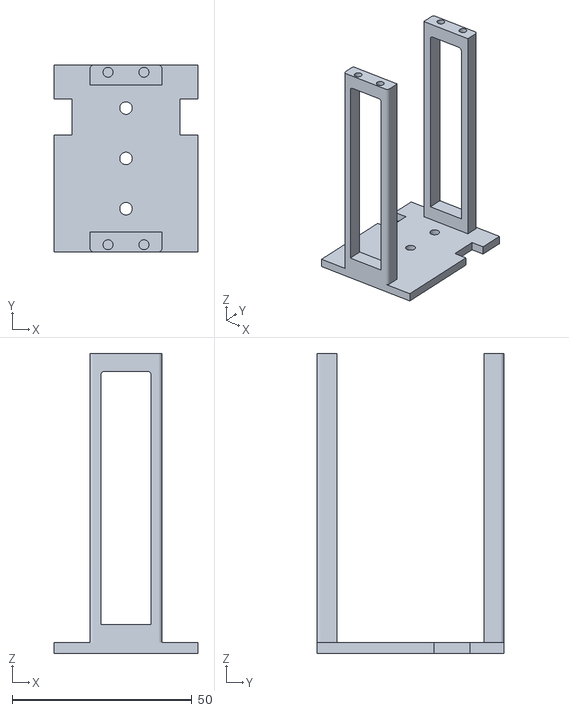
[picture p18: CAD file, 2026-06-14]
3D Models/main 360 servo support.stl
40.0 x 52.0 x 83.5

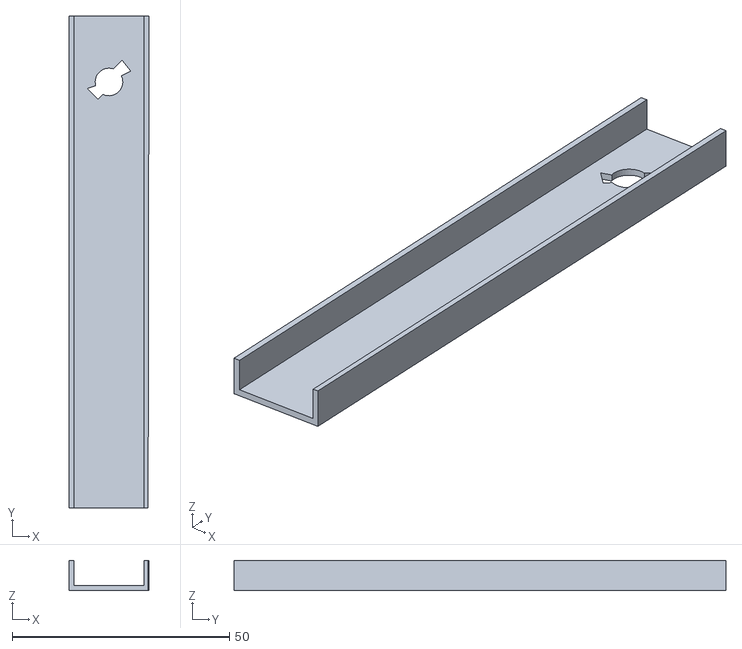
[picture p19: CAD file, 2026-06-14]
3D Models/main ramp.stl
18.4 x 113.2 x 7.00

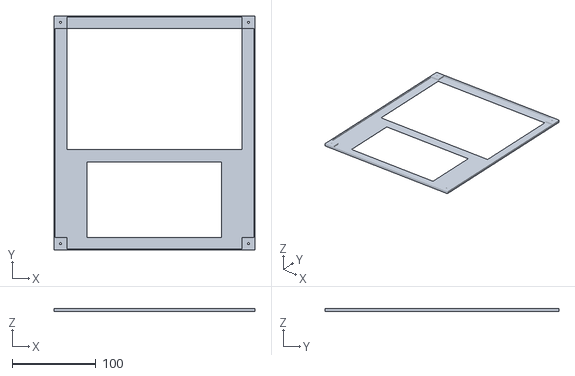
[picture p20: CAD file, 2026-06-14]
3D Models/roof.stl
240.0 x 280.0 x 4.00

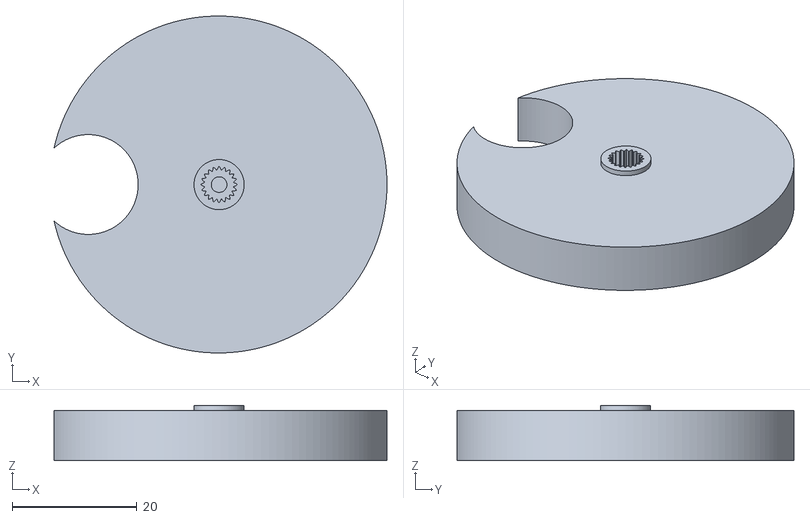
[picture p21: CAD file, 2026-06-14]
3D Models/rotative disc dispenser.stl
53.4 x 54.0 x 8.85

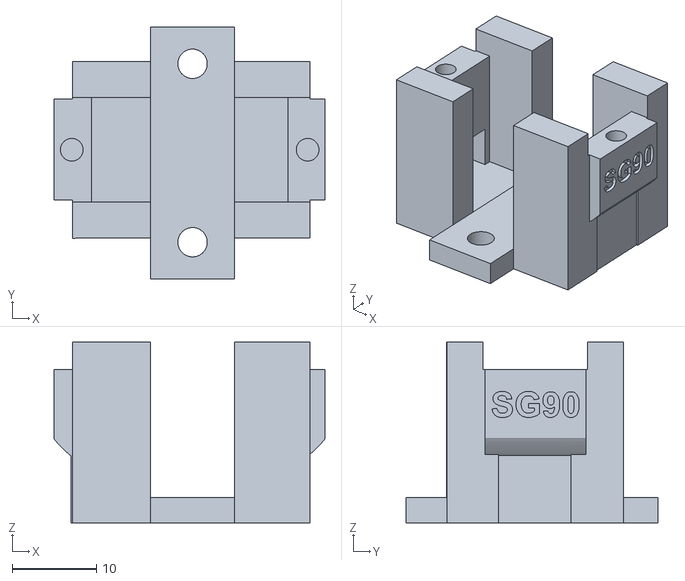
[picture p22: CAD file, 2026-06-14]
3D Models/ramp sg support.stl
32.2 x 30.0 x 21.5

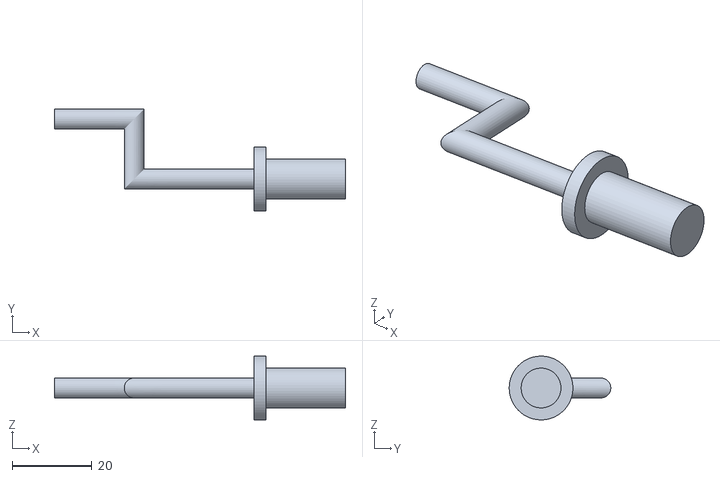
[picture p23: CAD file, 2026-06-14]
3D Models/crank.stl
73.0 x 25.5 x 16.0

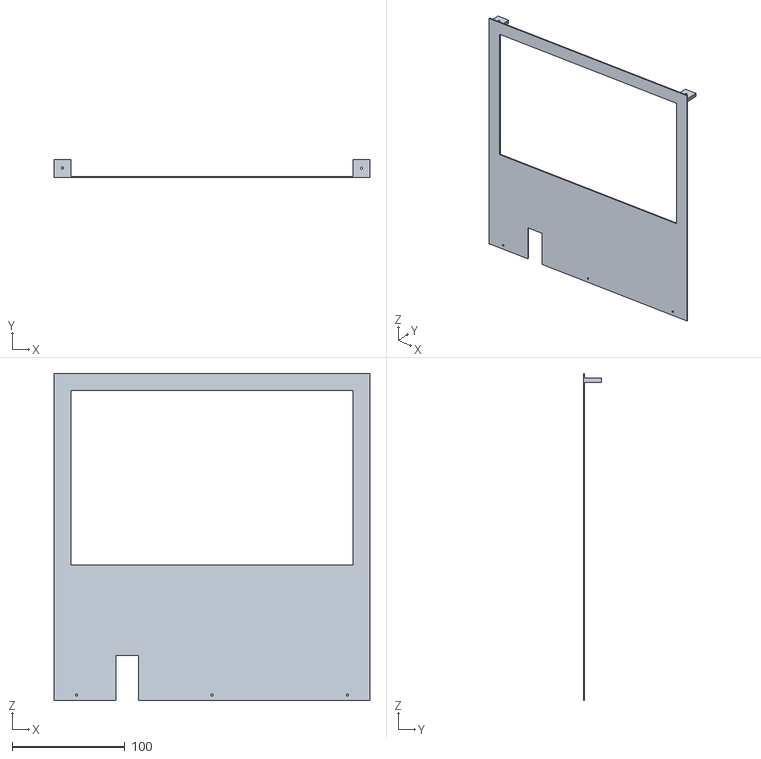
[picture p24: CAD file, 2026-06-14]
3D Models/right skin.stl
280.0 x 16.2 x 290.0

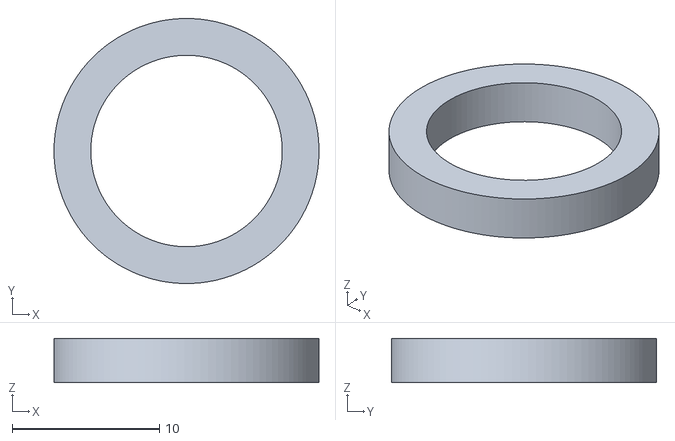
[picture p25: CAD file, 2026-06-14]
3D Models/crank limiter.stl
18.0 x 18.0 x 3.00

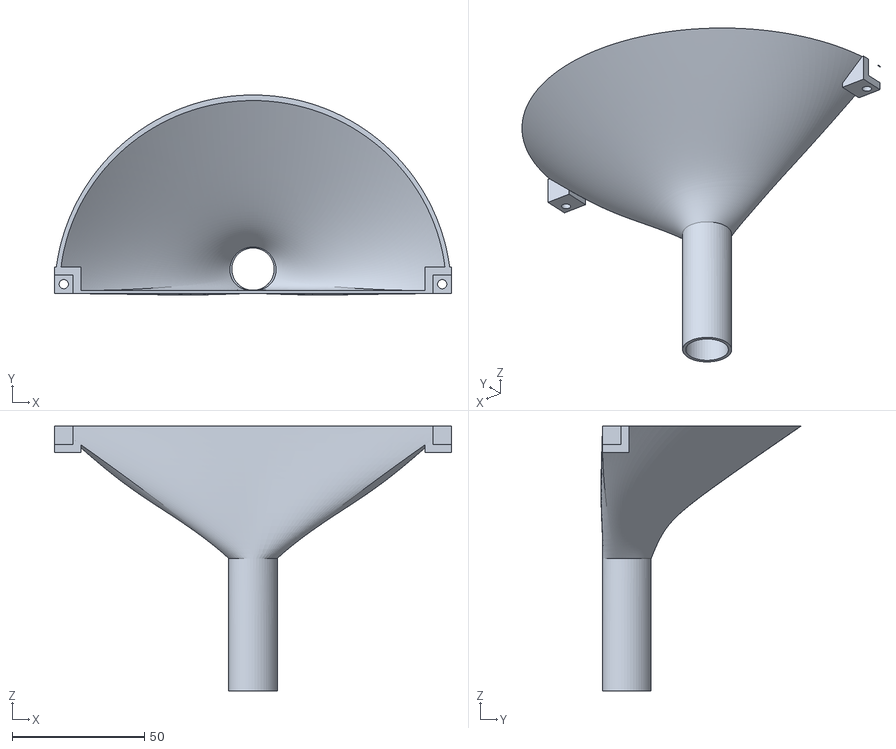
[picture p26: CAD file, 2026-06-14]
3D Models/funnel.stl
150.0 x 75.6 x 100.0

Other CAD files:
3D Models/funnel top support.stl
3D Models/funnel roof.stl
3D Models/dispenser sg support.stl
3D Models/left skin.stl
3D Models/adapter ramp to sg90.stl
3D Models/back skin.stl
3D Models/basic big support.stl
3D Models/bridge floor.stl
3D Models/bridge leg.stl
3D Models/cam support.stl
3D Models/dispenser skeleton.stl
3D Models/double leg big support.stl
3D Models/front skin.stl
3D Models/inverted dispenser sg support.stl
3D Models/inverted dispenser skeleton.stl
3D Models/ramp support.stl

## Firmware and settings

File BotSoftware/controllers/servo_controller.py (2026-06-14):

import time
from BotSoftware.config import servo_config as cfg

try:
    from adafruit_servokit import ServoKit
    _kit = ServoKit(channels=cfg.PCA9685_CHANNELS, address=cfg.PCA9685_ADDRESS)
    SIMULATION = False
except Exception as exc:
    _kit = None
    SIMULATION = True
    print(f"[servo] no hardware: {exc}")

_initialized = False


def _setup_sg90(channel):
    if SIMULATION:
        return
    servo = _kit.servo[channel]
    servo.actuation_range = cfg.SG90_RANGE
    servo.set_pulse_width_range(cfg.SG90_PULSE_MIN, cfg.SG90_PULSE_MAX)


def _set_angle(channel, angle):
    if SIMULATION:
        print(f"[servo] ch{channel} -> {angle} deg")
        return
    _kit.servo[channel].angle = angle


def _set_angle_slow(channel, angle, step=2, delay=0.02):
    if SIMULATION:
        print(f"[servo] ch{channel} -> {angle} deg (slow)")
        return
    current = _kit.servo[channel].angle or 0
    step = step if angle > current else -step
    for a in range(int(current), int(angle), step):
        _kit.servo[channel].angle = a
        time.sleep(delay)
    _kit.servo[channel].angle = angle


def disk_start():
    if SIMULATION:
        print("[servo] disk start")
        return
    _kit.continuous_servo[cfg.DISK_CHANNEL].throttle = cfg.DISK_SPEED


def disk_stop():
    # duty_cycle = 0 cuts the pulse entirely; throttle = 0 only sends a neutral
    # pulse that a continuous servo keeps reading as slow rotation.
    if SIMULATION:
        print("[servo] disk stop")
        return
    _kit._pca.channels[cfg.DISK_CHANNEL].duty_cycle = 0


def _ensure_init():
    global _initialized
    if _initialized:
        return
    _setup_sg90(cfg.RAMP_CHANNEL)
    for d in cfg.DISPENSERS.values():
        _setup_sg90(d["channel"])
    _set_angle(cfg.RAMP_CHANNEL, cfg.RAMP_CENTER_ANGLE)
    for d in cfg.DISPENSERS.values():
        _set_angle(d["channel"], d["rest"])
    _initialized = True


def ramp_to(color):
    _ensure_init()
    _set_angle(cfg.RAMP_CHANNEL, cfg.RAMP_ANGLES[color])
    time.sleep(cfg.RAMP_SETTLE_S)


def ramp_center():
    _ensure_init()
    _set_angle(cfg.RAMP_CHANNEL, cfg.RAMP_CENTER_ANGLE)
    time.sleep(cfg.RAMP_SETTLE_S)


def dispense(color, qty=1):
    _ensure_init()
    d = cfg.DISPENSERS[color]
    for _ in range(qty):
        _set_angle_slow(d["channel"], d["dispense"], cfg.DISPENSER_STEP, cfg.DISPENSER_STEP_MS)
        time.sleep(cfg.DISPENSER_HOLD_S)
        _set_angle_slow(d["channel"], d["rest"], cfg.DISPENSER_STEP, cfg.DISPENSER_STEP_MS)
        time.sleep(cfg.DISPENSER_GAP_S)


if __name__ == "__main__":
    _ensure_init()
    for c in cfg.DISPENSERS:
        dispense(c, qty=1)

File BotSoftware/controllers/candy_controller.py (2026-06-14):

from BotSoftware.controllers import servo_controller
from BotSoftware.controllers import display_controller as display
from BotSoftware.models.candy_stock import check_availability, consume_from_command


def dispense(items):
    """Dispense the requested items, if there's enough stock."""
    if not items:
        display.empty_command()
        return

    check = check_availability(items)
    if not check["ok"]:
        for m in check["missing"]:
            print(f"  {m['color']}: demanat {m['requested']}, disponible {m['available']}")
        m = check["missing"][0]
        display.low_stock(m["color"], m["available"])
        return

    for item in items:
        color, qty = item["color"], item["quantity"]
        print(f"  Dispensant {qty}x {color}")
        display.dispensing(color, qty)
        servo_controller.dispense(color, qty)

    consume_from_command(items)
    display.served()

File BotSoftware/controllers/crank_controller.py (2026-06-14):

# Reed switch on a GPIO. Turning the crank moves a magnet past it -> pulses.
# First pulse after idle  = crank started -> start recording.
# No pulses for IDLE_TIMEOUT = crank stopped -> stop recording and send audio.

import time

REED_PIN     = 17     # BCM pin wired to the reed switch
IDLE_TIMEOUT = 2.0    # seconds without pulses -> crank considered stopped
BOUNCE_S     = 0.01   # reed switch debounce
POLL_S       = 0.05
SIM_TURN_S   = 4.0    # simulated cranking duration when there's no hardware

try:
    from gpiozero import Button
    _reed = Button(REED_PIN, pull_up=True, bounce_time=BOUNCE_S)
    SIMULATION = False
except Exception as exc:
    _reed = None
    SIMULATION = True
    print(f"[crank] no hardware: {exc}")

_last_pulse = 0.0


def _on_pulse():
    global _last_pulse
    _last_pulse = time.time()


if not SIMULATION:
    _reed.when_pressed = _on_pulse


def is_turning():
    """True while pulses keep arriving (crank still moving)."""
    window = SIM_TURN_S if SIMULATION else IDLE_TIMEOUT
    return time.time() - _last_pulse < window


def wait_for_turn():
    """Block until the crank starts turning."""
    global _last_pulse
    if SIMULATION:
        print("[crank] (sim) cranking started")
        _last_pulse = time.time()
        return
    while not is_turning():
        time.sleep(POLL_S)

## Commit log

2026-05-05 Add system architecture and materials documentation
    Document the system architecture and hardware components for CandyBot.
2026-05-12 Create detectar_skittle.py
    Codi V1 de detecció de color a través de càmera
2026-05-19 Delete Software/VC/detectar_skittle.py
    Ara penjaré la nova versió
2026-05-19 Update readme.txt
    Readme actualitzat sobre el codi de VC
2026-05-19 Detecció dels colors amb VC
    Amb imatges de prova fetes amb la camara de la Raspberry, fem detecció automàtica per colors amb VC
2026-05-19 Nom de carpetes actualitzat, implementat mvc, primera versio de codi
2026-05-29 Codi servo bàsic
2026-06-01 control servo ServoKit
2026-06-01 script bàsic de pantalla
2026-06-01 servo configs
2026-06-01 Print a pantalla LCD
2026-06-03 Integrate servo control with speech recognition results
    Added servo control functionality for dispensing items based on speech recognition results.
2026-06-14 Rework robot software: restructure repo and wire the full flow
    - Split the codebase by deployment target: BotSoftware/ runs on the Raspberry
    Pi, Api/ is the standalone Cloud Run service, HW tests/ holds per-component
    hardware checks.
    - Move the dispensing, sorting and LCD logic into modular controllers
    (servo, lcd, crank, vision) instead of a single script.
    - Add the crank (reed switch) as the recording trigger and a main loop that
    listens, then dispenses or refills based on the voice command.
    - Add a self-sorting reload flow with a background voice-cancel listener.
    - Track stock in SQLite: show running totals while refilling and refuse
    requests with insufficient stock.
    - Rewrite t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
    [candy_controller.py, crank_controller.py]
2026-06-14 Calibrate dispenser angles
2026-06-14 cambio en el funcionamiento del disco, a rotacion continua con 4 slots
2026-06-14 added our in-house 3D models
    [adapter ramp to sg90.stl, assembly dispenser (non-printable).stl, back skin.stl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]
